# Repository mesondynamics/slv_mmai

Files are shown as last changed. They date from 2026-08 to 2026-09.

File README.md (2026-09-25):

# Mobile Machine Actuation Interface

**English** · [简体中文](README.zh-CN.md)

A hardware/software interface for retrofitting remote or autonomous control onto
electromechanical and electrohydraulic mobile machines.

MMAI command, actuation, and feedback architecture

MMAI connects an upper-level controller to the steering, propulsion, auxiliaries,
and available state feedback of an existing machine. This repository presents
the engineering approach through schematics, firmware, interface code, and its
development history. Read the source as working design material: it records the
hardware, communication, and actuation choices behind the ECU.

## What it does

- Receives commands from teleoperation or autonomy software.
- Validates commands and manages control authority, timeouts, and output enable.
- Maps commands to electrical interfaces such as relays, CAN-controlled actuators,
  or PWM-driven hydraulic valve coils.
- Acquires machine and actuator state and sends feedback to the upper layer.
- Keeps low-level machine behavior understandable independently of a planner.

The same architecture can be adapted to street sweepers, compactors, agricultural
machines, utility vehicles, and other mobile equipment. The appropriate actuator,
wiring, feedback, and stop behavior depend on the machine. Analog command outputs
or additional serial interfaces are adaptation options, not capabilities implied
for every board in this repository.

## Architecture

The machine-interface ECU sits between the command source and the physical
machine. Steering, propulsion, and auxiliary I/O are separate adaptation paths;
state feedback closes the path through the ECU. Existing manual controls and
machine interlocks are part of that integration.

Upper-level navigation, perception, and route planning are outside the core
actuation boundary. The retained implementation focuses on low-level actuation
and state feedback. See [Architecture](docs/architecture.md)
and [Interfaces](docs/interfaces.md).

## Implementation map

| Area | Start here | What to look for |
| --- | --- | --- |
| H563 actuation ECU | [Hardware project](pcb/roller/ecu/PROJECT1.kicad_pro), [firmware](firmware/roller/ECU/) | Relay switching, proportional-valve current control, CAN steering, protected control boundary |
| Mechanical material | [CAD](cad/), [PCB sources](pcb/) | Physical integration and board development |

Historical directory names are retained so code, drawings, and commits remain
easy to trace. They do not define the scope of the general architecture.

## A useful reading order

1. Read the [hardware guide](docs/hardware.md) and open the corresponding schematic.
2. Follow a command through the [firmware guide](docs/firmware.md): parser, control
   policy, machine mapping, then physical driver.
3. Follow feedback in the opposite direction, checking units and validity flags.
4. Compare earlier revisions using the [project history](docs/PROVENANCE.md).
5. Use the [porting guide](docs/porting-guide.md) to describe a different machine.

The H563 example includes an Ethernet command/state protocol, CAN interfaces,
relay/contact outputs, PWM valve drivers with current sensing, and analog,
discrete, and pulse inputs. Its wire protocol and I/O assignments are concrete
implementation choices; they are not a universal machine API.

## Safety and bench exploration

This is experimental engineering material, not a certified functional-safety
controller or a ready-to-install vehicle conversion. Physical deployment needs
machine-specific engineering. Begin any electrical exploration with isolated
signals and dummy loads, and understand startup, command-loss, manual-control,
and emergency-stop behavior before connecting actuators. See [Safety](docs/SAFETY.md).

## History and related work

The repository lineage begins in 2024. The public source centers on the
machine-interface ECU hardware and firmware, with retained design revisions
and technical notes. [Provenance](docs/PROVENANCE.md) identifies source milestones.

Electronic and electrohydraulic machine actuation has a long public engineering
history. [Prior art and related systems](docs/PRIOR_ART.md) provides technical
references for understanding these established approaches.

## License and contributions

Original project contributions use [BSD-2-Clause](LICENSE), subject to existing
file-specific notices. Bundled third-party material retains its own terms and
attribution; see the [license index](LICENSES/README.md).

Corrections, explanations, and clearly attributed design contributions are welcome.
See [Contributing](CONTRIBUTING.md) and [Security](SECURITY.md).

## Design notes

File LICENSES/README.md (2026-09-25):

# License scope and existing notices

The root [BSD-2-Clause license](../LICENSE) covers original MMAI contributions,
including original source, design files, and documentation, except where a file
already specifies other terms. "MMAI contributors" refers to the respective
contributors; existing copyright notices and author attribution remain in force.

The root license does not relicense third-party source, documents, images,
libraries, or models. Their respective notices and terms continue to apply.

| Component or collection | Existing notice |
| --- | --- |
| H563 Arm CMSIS | [CMSIS license](../firmware/roller/ECU/Drivers/CMSIS/LICENSE.txt) |
| H563 ST device support | [Device license](../firmware/roller/ECU/Drivers/CMSIS/Device/ST/STM32H5xx/LICENSE.txt) |
| H563 ST HAL | [HAL license](../firmware/roller/ECU/Drivers/STM32H5xx_HAL_Driver/LICENSE.txt) |
| LAN8742 support | [Component license](../firmware/roller/ECU/Drivers/BSP/Components/lan8742/LICENSE.md) |
| LwIP | [COPYING](../firmware/roller/ECU/ThirdParty/LwIP/COPYING) |
| ECU LIB1 collection | [Supplied library terms](../pcb/roller/ecu/libraries/LIB1/LICENSE1.txt) |

This index points to existing notices; individual files and other hardware
generations may carry additional notices. References to external work are
attribution, not a change to that work's license.

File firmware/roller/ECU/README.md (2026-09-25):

# STM32H563 actuation ECU firmware

[MMAI overview](../../../README.md) · [Firmware reading guide](../../../docs/firmware.md)

This project implements an actuation interface with Secure and NonSecure firmware
domains, an Ethernet command/state interface, relay outputs, proportional-valve
current control, and CAN-connected machine/actuator paths.

## Read the implementation

| Area | Entry point |
| --- | --- |
| Command framing and parsing | [ecu_protocol.h](NonSecure/App/Inc/ecu_protocol.h), [ecu_protocol.c](NonSecure/App/Src/ecu_protocol.c) |
| Network handling | [ecu_network.c](NonSecure/App/Src/ecu_network.c) |
| Protected interface | [safety_api.h](Secure_nsclib/safety_api.h) |
| Output policy and interlocks | [safety_service.c](Secure/App/Src/safety_service.c), [run_permit_policy.c](Secure/App/Src/run_permit_policy.c) |
| Valve-current loop | [valve_control.c](Secure/App/Src/valve_control.c) |
| Steering control | [steering_control.c](Secure/App/Src/steering_control.c), [steering_can.c](Secure/App/Src/steering_can.c) |
| Machine CAN feedback | [vehicle_can.c](Secure/App/Src/vehicle_can.c) |
| Boot/update layout | [ecu_flash_layout.h](Shared/ecu_flash_layout.h), [OEMiROT](Bootloader/OEMiROT/) |

Trace each requested output through the parser, authority/enable policy, machine
mapping, and driver. For feedback, trace the physical input through scaling,
validity/freshness, and state encoding. Manual run permission and automatic-output
enable are distinct decisions in this implementation.

## Design context

The project contains STM32CubeMX/CMake inputs, vendor support, host tools, and
historical tests. They describe a particular hardware generation and its original
engineering assumptions. Device profiles and wiring mappings are examples of
integration-specific configuration, not universal defaults.

The retained detailed notes include the original Chinese
[protocol and UI description](docs/ECU_Protocol_and_UI.md),
[boot/update design](docs/ECU_Security_and_OTA.md), and
[bench-method notes](docs/ECU_Bench_Acceptance.md). The English
[interface guide](../../../docs/interfaces.md) gives the main protocol boundaries.

Before using manufacturing, recovery, update, or control tools, understand their
physical effects and the target hardware. See [Safety](../../../docs/SAFETY.md).

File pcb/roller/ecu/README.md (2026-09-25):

# Actuation interface ECU hardware

**English** · [中文设计说明与完整参考资料](README.zh-CN.md)

This STM32H563-based board illustrates the electrical boundary between an
upper-level controller and existing machine actuators and sensors. Open
[PROJECT1.kicad_pro](PROJECT1.kicad_pro) and the
[root schematic](PROJECT1.kicad_sch) to explore the design.

The [hardware reading guide](../../../docs/hardware.md) maps the nine schematic
sheets to their functions. The [architecture](../../../docs/architecture.md)
places the board in the larger steering, propulsion, and auxiliary-I/O system.

## Design paths

- **Steering:** connect to a supported external actuator/controller; mechanical
  coupling and feedback depend on the machine.
- **Propulsion:** the reference circuit drives two proportional-valve coils with
  PWM and current sensing. The machine's hydraulic circuit determines how coil
  current affects propulsion.
- **Auxiliaries:** a serial driver chain and relay contacts can switch or select
  existing machine signals. Wiring and contact assignments remain machine-specific.
- **Feedback:** analog, temperature, isolated digital, pulse, and bus interfaces
  provide the inputs available to the selected integration.

## Circuit-source notes

The original [Chinese technical notes](README.zh-CN.md) include the detailed
PAGE1-PAGE9 circuit mapping, public source identifiers S01-S60, and illustrated
retrofit examples. Selected entry points are:

| Topic | Detailed notes |
| --- | --- |
| Steering actuators | [Motor/steering integration](README.zh-CN.md#steer-sys-01) |
| Proportional-valve drive | [PWM and current-sensing path](README.zh-CN.md#sol-os-01) |
| Relay/contact switching | [Relay interface path](README.zh-CN.md#rly-sys-01) |
| Solenoid reference circuit | [Analog Devices CN0415](README.zh-CN.md#s38) |
| Earlier hydraulic retrofit example | [CASE CX160 project reference](README.zh-CN.md#s60) |

These references explain particular design functions; they do not make all
machine interfaces interchangeable. Consult the selected board revision and
[safety guidance](../../../docs/SAFETY.md) before any physical integration.

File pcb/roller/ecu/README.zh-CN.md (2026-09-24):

# 通用车辆线控改装方案

本项目整理公开的车辆改装方法，并提供一套可复用的开源 ECU 硬件设计。目标是让具备不同转向、行驶和车身信号机构的车辆，经过针对车型的适配后，能够接收外部控制命令并返回状态，从而成为遥控或无人驾驶系统的车辆执行平台。执行装置、原车接口和可获得的反馈都以目标车辆为准。

## 整体方案

车辆线控系统整体架构

转向、行驶和车身信号是三条可分别适配的路径。ECU 接入命令、连接外部执行装置或原车接口，并汇集可取得的状态反馈。遥控与无人驾驶的区别在于命令来源。

## 车辆改装方案

### 转向：电机方向盘

在方向盘位置安装同轴直驱的电机方向盘，使电机通过原车转向柱和转向机构完成转向，并读取电机位置或可用的转角反馈。中空轴/中空电机是可选的机械安装形式；轴径、花键、安装空间与所需扭矩应按车型和所选电机确定。

| 公开案例 | 改装形式 | 对本方案的参考 |
| --- | --- | --- |
| [Keya 工程车辆转向电机](#s51) | 安装于转向轴的直驱电机；资料列举叉车、压路机、推土机 | 工程车辆的电机方向盘路线 |
| [SunNav AG500Pro](#s52) | 电机方向盘替换原方向盘 | 农机的方向盘替换路线 |
| [Smajayu JY305](#s53) | 电机方向盘配合控制器和角度传感器 | 转向执行与角度反馈的组合路线 |

| Keya 转向电机套件 | SunNav AG500Pro 电机方向盘 | Smajayu JY305 装车示例 |
| :---: | :---: | :---: |
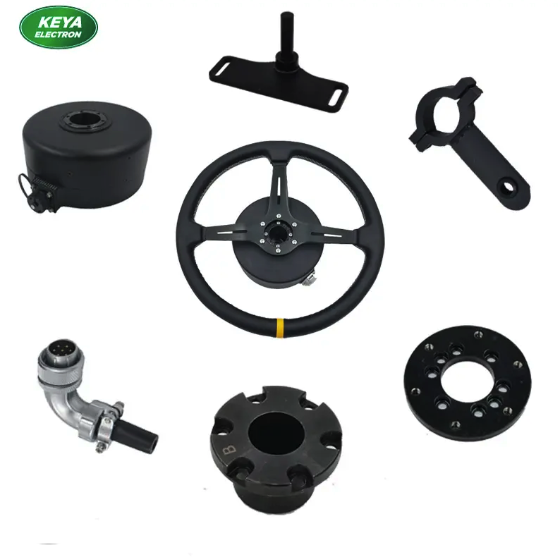
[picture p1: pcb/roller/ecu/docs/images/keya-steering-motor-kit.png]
Keya 转向电机与方向盘套件
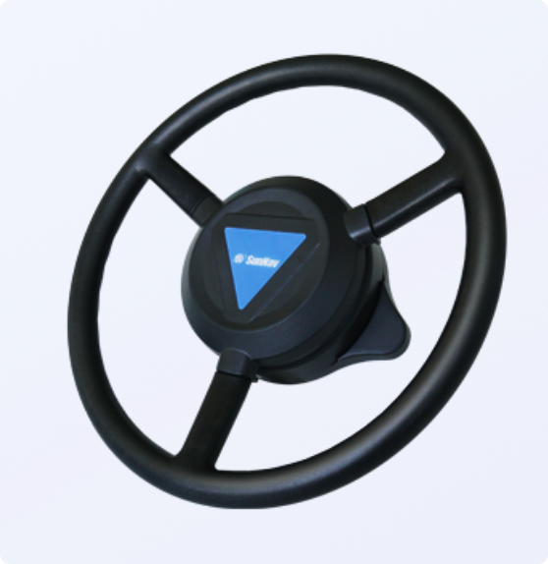
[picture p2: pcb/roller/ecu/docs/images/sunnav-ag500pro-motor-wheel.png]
SunNav AG500Pro 电机方向盘
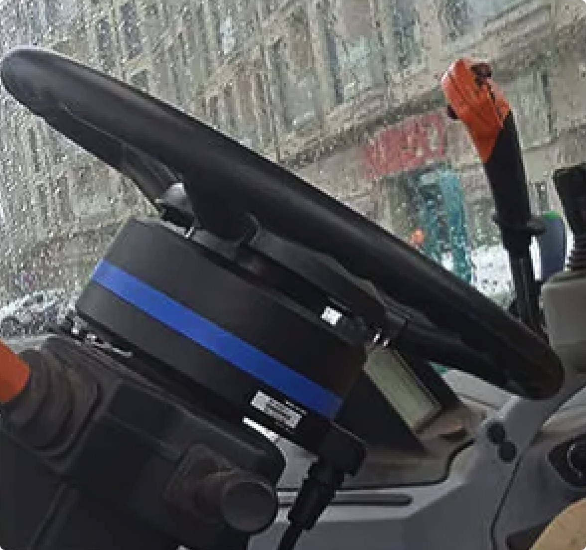
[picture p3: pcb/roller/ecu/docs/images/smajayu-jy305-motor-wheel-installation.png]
Smajayu JY305 电机方向盘装车示例
|  |  |  |

Keya 转向电机的[演示视频](https://www.youtube.com/watch?v=uilSU-zbLFg)。三张产品图分别对应 [S51](#s51)、[S52](#s52)、[S53](#s53)。

### 行驶与速度：本项目方案及其他公开路径

不同车辆接收油门、速度及前进/后退指令的机构不同。下表汇集相应的公开改装路径，供其他车型选择与溯源；**本项目针对所用车辆选择的是在低压先导油路增设比例阀**，本 ECU 设计了与之对应的两路阀线圈驱动和电流采样。其余路径仅为公开案例。

| 原车机构 | 改装路径  | 公开来源 |
| --- | --- | --- |
| 具有低压先导油路的液压行驶机构 | 在先导油路增设比例阀，通过阀线圈电流调节先导压力和原车主阀；具体行驶功能由原车液压回路决定 | [2003 年 CASE CX160 遥控改装](#s60)、[AgOpenGPS 液压硬件](#s48)、[OpenHumidistat 恒流驱动](#s49)、[ADI CN0415](#s38) |
| 机械油门或速度操纵杆 | 用执行器推动原控制件，行程与位置反馈按原车机构适配 | [ROS 2 Autonomous Tractor](#s59) 展示直线执行器控制加速 |
| 原车速度电位器 | 对可接入的速度设定信号，参考模拟速度指令接入方式 | [OpenPodcar](#s43) 展示原车速度电位器的电控接入 |
| 电子节气门或电驱控制器 | 在车型和控制器支持的条件下，使用其可验证的电子控制接口；具体接口依车型而定 | [rusEFI](#s54) 展示电子节气门链路；[OVCS](#s55) 展示电驱车辆多部件 CAN 集成 |

2003 年弗吉尼亚理工大学公开的 [CASE CX160 挖掘机遥控改装报告](#s60) 是液压车辆的实车案例：团队在原车低压先导油路增加电液比例阀，通过先导压力控制主阀，进而遥控左右履带和工作装置。报告还记录了液压改装、电气控制及实车调试。该案例说明比例阀路线早已用于工程车辆遥控改装；是否适用其他车辆，取决于其液压系统是否提供合适的先导控制接入点。

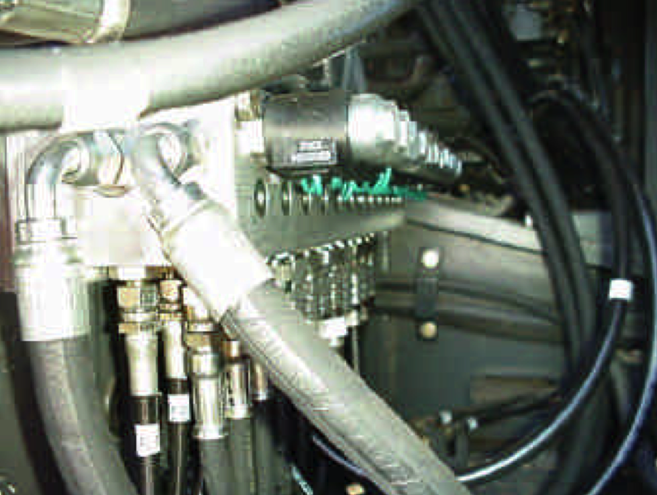
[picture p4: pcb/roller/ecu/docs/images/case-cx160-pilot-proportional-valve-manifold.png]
CASE CX160 挖掘机先导油路比例阀集成块实物


*图：CASE CX160 改装中的比例阀集成块实物；项目维护者提供的截图，参见 [2003 年改装报告](#s60) Figure 5-6。*

速度反馈与速度命令是不同的接口。公开方案中，车速可来自可解析的原车 CAN、车速脉冲或独立速度传感器；[RetroPilot Ocelot](#s56) 展示了原始 VSS 输入与已有 CAN 信息的转换。本项目车辆最终采用的车速反馈及前进/后退信号接法，仍需依据原车接口确定；上述来源不表示所有反馈路径均已在本 ECU 上完成接入。

### 灯光、喇叭与其他原车信号

对于需要切断原路径再切换到外部控制的信号，可用继电器接入；只需新增通断控制的信号，可按原车接口选用受控电源或接地。[OpenPodcar](#s43) 的车辆继电器接入与 [Subaru BRZ VCU](#s45) 的继电器、信号复用设计提供公开参考。

另一条路径是使用原车或已有线控系统提供的 CAN 接口。[PACMod3 公开驱动](#s58) 列出了灯光、喇叭、危险警示灯等命令；[opendbc](#s57) 展示车型相关的 CAN 消息定义。CAN 控制仅适用于已确认支持相应命令的车型或控制系统，不能把某车型的消息直接视为通用接口。继电器和 CAN 可在同一车辆上分别负责不同信号。

### 状态反馈

整车可按现有接口取得方向盘或车轮转角、车速、行驶执行装置状态、灯光/喇叭等原车信号状态。反馈可来自执行装置控制器、原车 CAN、车速脉冲、开关量或模拟传感器；公开的 [OVCS](#s55) 与 [RetroPilot Ocelot](#s56) 展示了多种原车与外加接口并用的方式。并非所有车辆都提供上述全部状态，实际可用项由车型接口确定。

## ECU：车辆连接中枢

ECU 接收外部命令，通过通信接口与外部执行装置或原车控制系统连接，通过自身输出连接点击、继电器及针对低压先导油路改装的两路比例阀，并采集可接入的模拟量、数字量和脉冲量。

### 比例阀驱动电路

本 ECU 的两路比例阀驱动主要面向**在车辆低压先导油路增设电液比例阀**的改装方式：PAGE7 为两个阀线圈提供低边驱动及电流采样硬件，通过调节先导压力影响原车主阀。此设计参考 [2003 年 CASE CX160 案例](#s60) 的液压接入思路；该案例使用 12 个阀及独立阀控制器，本 ECU 的两路硬件并非整套挖掘机液压控制系统。两路阀的用途、行驶方向映射及所需电流范围，仍由目标车辆的先导油路和主阀决定。

[ADI CN0415](#s38) 是比例电磁阀驱动的主要公开参考：其说明了 PWM、线圈电流监测、闭环控制和 dither。CN0415 采用低边开关与高边分流采样；本项目借鉴功能链路，在 PAGE7 使用低边分流采样。[S21](#s21)、[S39](#s39)、[S40](#s40)、[S41](#s41) 和 [S42](#s42) 补充电流检测与汽车比例阀资料。

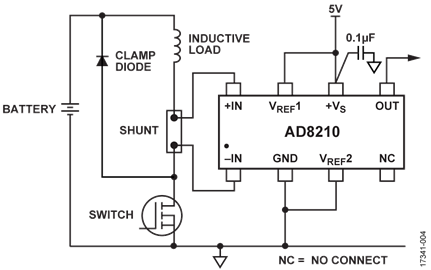
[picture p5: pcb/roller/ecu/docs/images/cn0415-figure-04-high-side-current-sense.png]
CN0415 高边电流采样与低边开关


*图源：[Analog Devices CN0415](https://www.analog.com/en/resources/reference-designs/circuits-from-the-lab/cn0415.html#rd-description)，Figure 4。*

本项目以 PWM 控制低边 MOSFET，并测量线圈电流；[OpenHumidistat](#s49)、[PneuSoRD](#s47) 和 [AgOpenGPS](#s48) 提供可追溯的公开实现参考。

### 继电器驱动与信号切换来源

PAGE5 的串行低边驱动链连接 PAGE6 的继电器触点。继电器可用于原车信号断开与替代信号切换，也可为无需切断的信号提供受控电源或接地；具体触点功能由车型连接表决定。[OpenPodcar](#s43)、[Subaru BRZ VCU](#s45) 和 [relay_matrix_edsp](#s46) 是公开系统参考，[TPIC6A595](#s13) 与 [SN74AHCT541-Q1](#s37) 提供驱动器件依据。

### 电路来源的使用方式

本文区分器件厂商资料、开源实现和公开商业产品。来源编号用于追溯。以下等级仅用于 ECU 电路的来源映射。

| 等级 | 含义 | 在本项目中的用途 |
| --- | --- | --- |
| A | 同型号器件的官方典型应用、参考原理图或评估板与本页拓扑近似 | 电路拓扑和关键连接依据 |
| B | 同型号官方数据手册/应用笔记给出的连接规则、接口电路或设计方法 | 局部电路、器件选型和控制方法依据 |
| C | 公开的通用原理、相邻型号资料或器件能力说明 | 工程实现方向，参数仍需验证 |

### ECU 电路与公开来源映射

下表按原理图 PAGE 列出 ECU 已有电路及公开依据。

### PAGE1 — 电源变换与状态指示

| ID | 电路与覆盖范围 | 公开依据（文档定位） | 等级 | 本项目实现说明 |
| --- | --- | --- | --- | --- |
| P1-01 | 高电流同步降压：`U8`、`L2` 及其输入、输出、反馈、频率设定和去耦网络 | [S01](#s01)，Figure 10，p.69 | A | 同为 MPQ4371-1000 的 5 V、2.2 MHz 典型应用；反馈、频率设定、输入/输出电容结构高度一致。工程中的器件额定值、并联数量及使能/模式配置需以原理图和负载验证为准。 |
| P1-02 | 小功率同步降压：`U9`、`L1` 及 `C7,C10-C12,C14-C18,C23,C25,C26,R23-R30,R32,R33,R50,R60,R61,R64` | [S02](#s02)，Application Information 与 Typical Application Circuits，pp.21–25 | A | 拓扑、软启动、反馈、输入/输出去耦与 MPQ2178 典型应用一致。 |
| P1-03 | 两组电源良好/状态指示与开漏缓冲：`Q1,Q9,D7,D14,R34,R35,R63,R65,R66` | [S01](#s01)，Power Good；[S02](#s02)，Power Good；[S15](#s15)，MOSFET switching application | B | 本项目依据开漏状态输出和外部上拉规则设计 LED 与小信号 MOSFET 指示级，具体电阻和指示方式由工程需求确定。 |

### PAGE2 — MCU、时钟、复位、调试与安全器件

| ID | 电路与覆盖范围 | 公开依据（文档定位） | 等级 | 本项目实现说明 |
| --- | --- | --- | --- | --- |
| P2-01 | MCU 供电、模拟参考、内部稳压电容与就地去耦：`U1` 及 `C6,C28-C46,C51,R36,R37` | [S03](#s03)，Figures 2、15、19，pp.5、36、40 | A | AN5711 明确覆盖 STM32H563 系列的电源域、参考设计和去耦布局；具体电容分配需结合所用封装引脚逐项核对。 |
| P2-02 | 外部复位按键、上拉/滤波与 ESD：`SW1,D1,R49,C46` | [S03](#s03)，Figure 9，p.15；[S28](#s28) | B | 复位网络符合 STM32H5 硬件指南，ESD 器件能力由其官方数据手册支持；保护等级仍取决于布局与脉冲源阻抗。 |
| P2-03 | 启动配置跳线：`JP1` 及相邻配置电阻 | [S03](#s03)，Boot configuration，p.26 | B | 文档给出启动脚配置原则；跳线形式及默认状态是工程选择。 |
| P2-04 | 25 MHz 高速外部晶振：`Y2,C47,C48` | [S04](#s04)，§§3–4（Pierce oscillator、load capacitance、crystal selection） | B | 结构符合 Pierce 振荡器；负载电容必须按晶体 CL、引脚和 PCB 寄生重新核算。 |
| P2-05 | 32.768 kHz 低速外部晶振：`Y1,C49,C50` | [S04](#s04)，§§3–4；[S03](#s03)，clock recommendations | B | 结构与低速晶体网络一致；低功耗晶体的驱动裕量和负阻测试不由原理图本身证明。 |
| P2-06 | SWD 调试接口：`J1` | [S03](#s03)，Figure 12，p.30 | A | 信号集合与 STM32H5 官方 SWD 连接方式一致；连接器针序是项目实现。 |
| P2-07 | I²C 安全器件及去耦/上拉：`U221,R105,R106,C45` | [S05](#s05)，Figure 1 与 Table 1；[S06](#s06)，DT100104 schematic，sheet 1 | A | 官方板原理图展示 ATECC608C 的 I²C、上拉和 100 nF 去耦。地址/配置区内容不在原理图可追溯范围内。 |

### PAGE3 — 10/100 Ethernet PHY 与物理接口

| ID | 电路与覆盖范围 | 公开依据（文档定位） | 等级 | 本项目实现说明 |
| --- | --- | --- | --- | --- |
| P3-01 | RMII PHY、偏置、内部稳压电容与电源滤波：`U4,FB1,R53,C54-C63` 及相邻去耦 | [S07](#s07)，p.13 与 Figures 3-20、3-21，pp.53–54 | A | 12.1 kΩ RBIAS、内部 1.2 V 稳压电容和单电源连接与 LAN8742A 官方应用图一致。 |
| P3-02 | PHY 25 MHz 晶振：`Y3,C52,C53` | [S07](#s07)，clock/oscillator sections；[S04](#s04)，§§3–4 | B | PHY 数据手册规定时钟接口，AN2867提供晶体负载核算方法；实际起振裕量需测试。 |
| P3-03 | MDI 端接、共模磁性器件与外部连接器：`R58,R59,R67,R68,R54-R56,C64,T201,J3` | [S07](#s07)，Figure 3-23，p.56；[S08](#s08)；[S09](#s09) | A | 49.9 Ω 端接、磁性器件、Bob Smith 类端接与官方单电源双绞线接口图一致；连接器由项目改为 M12 X-code，针序须按其图纸核对。 |
| P3-04 | 高速线 ESD 保护：`U5` | [S10](#s10)，Application Diagrams 与 PCB layout recommendations | B | USBLC6-4 的低电容多线保护结构可用于高速差分接口；具体 IEC 等级依赖布局，且该器件名称并不把用途限定为 USB。 |
| P3-05 | PHY 状态 LED 与串联电阻：`D19,D20,R51,R57` | [S07](#s07)，LED pins/configuration | B | PHY 提供 LED 输出及配置说明；颜色、亮度和电阻值为工程选择。 |
| P3-06 | RMII 串联阻尼/配置电阻：`R38-R48,R69,R70,R113-R115` | [S07](#s07)，RMII interface、strap inputs 与 layout guidance | B | 数据手册支持启动配置和数字接口布线原则；33 Ω 阻尼值须结合走线阻抗和边沿测量确认。 |

### PAGE4 — 两路 CAN 物理层

| ID | 电路与覆盖范围 | 公开依据（文档定位） | 等级 | 本项目实现说明 |
| --- | --- | --- | --- | --- |
| P4-01 | 两个同构 CAN 收发与可配置 120 Ω 端接通道：`U13,U14,C40,C85,R42,R43,R107,R108` | [S11](#s11)，Figures 38–39，p.27 | A | 官方图给出 CAN 总线与 120 Ω 端接原则；0 Ω 配置电阻使端接是否接入由装配方案决定。该物理接口可连接具备 CAN 接口的外部装置或经确认的原车 CAN 总线；协议与总线分配按车型确定。 |
| P4-02 | 两路 CAN 线对浪涌/ESD 保护：`D21,D22` | [S12](#s12)，High-Speed/Fault-Tolerant CAN Surge Protection application figure | A | NUP2105L 官方应用图即为 CANH/CANL 双线保护；最终抗扰度仍需结合接地回路和 PCB 布局验证。 |

### PAGE5 — 继电器驱动逻辑与串行低边驱动

| ID | 电路与覆盖范围 | 公开依据（文档定位） | 等级 | 本项目实现说明 |
| --- | --- | --- | --- | --- |
| P5-01 | 继电器驱动前端与四片低边驱动器组合链：`U300,U301-U304,Q6,C5,C21,C66-C68,R71-R78` | [S14](#s14)，Function Table、三态输出与电源建议；[S37](#s37)，SN74AHCT541-Q1 产品资料；[S13](#s13)，§7.3.3、§7.3.4，p.13 | B | 本项目使用 `SN74AHCT541QPWRQ1` 完成受使能控制的并行逻辑，使用 `TPIC6A595DWR` 完成串入并出、开漏低边输出、感性负载钳位和级联，形成四片低边继电器驱动链。 |
| P5-02 | TPIC 输出级及四片级联：`U301-U304,C5,C21,C66,C67,R71-R74` | [S13](#s13)，§7.3.3 与 §7.3.4 Cascaded Application，p.13 | A | SER OUT 到下一片 SER IN、低边开漏 DMOS 和感性负载钳位均由官方资料明确给出；负载数量与映射为工程定制。 |
| P5-03 | 小信号 MOSFET 控制/电平处理：`Q6,R77` | [S15](#s15)，Description and Applications | C | 本项目依据器件的开关和电源管理能力完成电平处理，Q6/R77 的阈值、速度和负载条件在样机测试中验证。 |

### PAGE6 — 继电器触点矩阵与电源储能

| ID | 电路与覆盖范围 | 公开依据（文档定位） | 等级 | 本项目实现说明 |
| --- | --- | --- | --- | --- |
| P6-01 | 继电器触点矩阵：`K1-K27` | [RLY-SYS-01](#rly-sys-01)；[S16](#s16) | — | 本项目重点记录矩阵的驱动、切换行为和安全时序；逐触点组合由工程连接表维护，车辆信号断开、替代切换、直接电源/地接入见 RLY-SYS-01。 |
| P6-02 | 继电器电源母线储能：`C22,C69-C71` | [S17](#s17)，Input and Output Capacitor Selection，bulk-capacitance discussion | C | 并联大容量电容符合负载阶跃储能的一般原则；容量、ESR、纹波电流、浪涌及故障能量必须按实际继电器同时动作数验证。 |

### PAGE7 — 两路功率低边驱动与电流检测

| ID | 电路与覆盖范围 | 公开依据（文档定位） | 等级 | 本项目实现说明 |
| --- | --- | --- | --- | --- |
| P7-01 | 两个比例电磁阀低边驱动通道：`U10,U11,Q2,Q3,D2,D3,R79-R82,C72-C75` | [比例阀低边恒流驱动](#sol-os-01)；[S38](#s38)；[S18](#s18)，Typical Application；[S19](#s19)；[S20](#s20) | B | 本项目采用 UCC27517A-Q1 控制 N-MOSFET，STPS5L60SY 提供续流路径，并以闭环电流建立比例阀控制量；CN0415 提供 PWM、dither、栅极驱动和过流保护的系统级参考。 |
| P7-02 | 两路 50 mΩ 分流电阻与 INA240 电流检测：`R1,R2,U6,U12,R83,R84,C76,C77` | [比例阀低边恒流驱动](#sol-os-01)；[S38](#s38)；[S21](#s21)，§9.2.2、§9.3.2；[S22](#s22) | B | 本项目采用 INA240 的 PWM 抑制和 Kelvin 采样方法；分流器为 50 mΩ、3 W，采样增益、量程、功耗和滤波按实际阀线圈验证，功能链路对应 CN0415 的电流监测和闭环控制。 |

### PAGE8 — 模拟量、温度、隔离量与脉冲输入

| ID | 电路与覆盖范围 | 公开依据（文档定位） | 等级 | 本项目实现说明 |
| --- | --- | --- | --- | --- |
| P8-01 | 四个同构的受保护模拟输入：`D4,D9,R85,R86,R94,C78`；`D12,D13,R91,R97,R98,C82`；`D15,D16,R99-R101,C83`；`D17,D18,R102-R104,C84` | [S23](#s23)，ADC input impedance/RC guidance；[S24](#s24)；[S25](#s25) | B/C | 本项目采用分压、串联限流、RC 低通和轨钳位构成 MCU ADC 前端；`ESD5V0D5` 当前按同型号公开参数建库，最终订货号在 BOM 阶段确认。 |
| P8-02 | 两个同构 NTC 分压/滤波输入：`J2,R109,R110,C86`；`J4,R111,R112,C87` | [S26](#s26)，Monitoring NTC Thermistor Circuit With Single-Ended ADC | B | 电阻分压与 ADC 输入电容的结构一致；NTC 的 B 值、标称阻值、线束电阻和温度换算表须由实际探头补充。 |
| P8-03 | 电源电压分压、RC 滤波与双肖特基钳位：`R92,R93,R95,R96,C79,D10` | [S23](#s23)，ADC input protection/RC guidance；[S24](#s24) | B | 结构符合高压量测的电阻分压和限流钳位原则；量程与故障注入电流需按 ADC 绝对最大额定值重新计算。 |
| P8-04 | 光耦隔离数字输入：`R117,R118,U15,R121,R122,C80` | [S27](#s27)，Figure 1 switching test circuit 与 electrical characteristics；[S31](#s31) | B | 输入限流、光晶体管输出上拉和滤波有器件/应用资料支持；阈值、CTR 老化裕量与现场电压范围是项目参数。 |
| P8-05 | 受保护的脉冲整形输入：`D8,R87,R88,D11,Q4,R89,C81,U7,R90` | [S29](#s29)，Schmitt-trigger input；[S30](#s30)；[S24](#s24) | B/C | 本项目使用 TVS/肖特基限制瞬态，使用 BJT 完成电平和电流处理，再由施密特反相器恢复边沿；整体按 C 级组合电路进行验证，各器件规则按 B 级执行。 |

### PAGE9 — 电源入口、反接保护与连接/机械件

| ID | 电路与覆盖范围 | 公开依据（文档定位） | 等级 | 本项目实现说明 |
| --- | --- | --- | --- | --- |
| P9-01 | 入口双向 TVS 与高低频旁路：`D5,C88,C89` | [S32](#s32)，SMCJ24CA-Q electrical characteristics；[S17](#s17) | B | 器件型号对应 24 V、1500 W、双向汽车级 TVS；电容并联用于宽频旁路。整机脉冲等级仍取决于源阻抗、线束和布局。 |
| P9-02 | 理想二极管控制器与外部 N-MOSFET 反接/反向电流保护：`U2,Q5` | [S33](#s33)，Typical Application Schematic 与 Figure 3；[S34](#s34) | A | LM74700-Q1 官方典型图即采用外部 N 沟道 MOSFET，并包含入口 TVS/电容；所选 60 V MOSFET 的耐压、导阻和热设计需针对实际浪涌复核。 |
| P9-03 | 两个密封板端连接器：`J6,J7` | [S35](#s35)；[S36](#s36) | A | 厂商页面/图纸分别确认 35 位和 23 位 AMPSEAL 直角板端连接器。针位的电气分配属于工程定义。 |
| P9-04 | 带焊盘安装孔：`H1-H4` | 本工程机械/接地实现，无唯一外部参考电路 | C | 位号覆盖完整；是否连接机壳、保护地或信号参考必须结合 PCB、结构和 EMC 方案判断。 |

## 公开来源

S01–S50 的访问日期为 **2026-09-17**；S51–S60 的访问日期为 **2026-09-24**。

### 开源实现来源

| 来源 | 许可证/开放方式 | 本项目采用的设计要点 |
| --- | --- | --- |
| [S43](#s43) OpenPodcar | 软件 GPL-2.0，硬件 CERN-OHL-W | 原车速度电位器/DAC 接入、转向执行器与继电器接入 |
| [S46](#s46) relay_matrix_edsp | MIT | 交叉点矩阵、级联驱动、互斥命令和状态查询 |
| [S47](#s47) PneuSoRD | MIT | 比例阀 PWM、降压功率级、过流保护和多通道驱动 |
| [S48](#s48) HW_for_AgOpenGPS | CERN-OHL-S-2.0（硬件） | 双 PWM 液压比例阀、反馈控制和开源农机执行器接口 |
| [S49](#s49) OpenHumidistat/hardware | CERN-OHL-S-2.0 | 两路低边 VCCS 恒流比例阀驱动、KiCad 原理图/PCB/BOM |
| [S50](#s50) OpenHumidistat 论文 | 公开论文与配套开源设计 | PWM 输入、恒流控制、温升补偿和比例阀闭环方法 |
| [S54](#s54) rusEFI | 公开项目与文档 | 电子节气门、踏板和节气门位置反馈 |
| [S55](#s55) OVCS | MIT | 电驱车辆的多部件 CAN 集成与状态读取 |
| [S56](#s56) RetroPilot Ocelot | 公开项目资料 | 原车 CAN、VSS 脉冲、继电器接口的组合 |
| [S57](#s57) opendbc | 开源项目 | 车型相关的 CAN 信号定义与解析 |
| [S58](#s58) PACMod3 驱动 | 公开驱动代码 | 支持平台的灯光、喇叭等车身命令接口 |
| [S59](#s59) ROS 2 Autonomous Tractor | 公开项目与文档 | 以直线执行器控制拖拉机加速的案例 |

### 公开商业产品案例

| 来源 | 公开案例 | 在整车方案中的用途 |
| --- | --- | --- |
| [S51](#s51) Keya | 工程车辆方向盘直驱电机 | 转向轴直驱、内置控制器和 CAN 接口参考 |
| [S52](#s52) SunNav AG500Pro | 农机电机方向盘 | 方向盘替换结构和外形、扭矩规格参考 |
| [S53](#s53) Smajayu JY305 | 农机自动转向套件 | 电机方向盘、控制器和角度传感器组合参考 |

### 公开学术改装案例

| 来源 | 实车案例 | 在整车方案中的用途 |
| --- | --- | --- |
| [S60](#s60) CASE CX160（2003） | 低压先导油路加装比例阀的挖掘机遥控改装 | 液压工程车辆的比例阀接入和实车应用参考 |

### 详细来源条目

本节列出机构/作者、文献题名、版本或章节定位和原始链接；具体电路与本项目的对应关系见上方 ECU 映射，整车使用方式见车辆改装方案。

**S01 — Monolithic Power Systems, MPQ4371-AEC1 Datasheet**, Rev. 1.0 (2024-03-21), Figure 10 “Typical Application Circuit for MPQ4371-1000”, p. 69.<br>
https://www.monolithicpower.com/en/documentview/productdocument/index/version/2/document_type/Datasheet/lang/en/sku/MPQ4371GVE-AEC1/

**S02 — Monolithic Power Systems, MPQ2178-AEC1 Datasheet**, Rev. 1.1 (2023-05-04), Application Information; Typical Application Circuits, pp. 21–25.<br>
https://www.monolithicpower.com/en/documentview/productdocument/index/version/2/document_type/Datasheet/lang/en/sku/MPQ2178GQHE-AEC1/

**S03 — STMicroelectronics, AN5711: Getting started with STM32H5 MCU hardware development**, Rev. 3, Figures 2, 9, 12, 15, 19.<br>
https://www.st.com/resource/en/application_note/an5711-getting-started-with-stm32h5-mcu-hardware-development-stmicroelectronics.pdf

**S04 — STMicroelectronics, AN2867: Oscillator design guide for STM8AF/AL/S, STM32 MCUs and MPUs**, Rev. 21, §§ 3–4.<br>
https://www.st.com/resource/en/application_note/an2867-oscillator-design-guide-for-stm8afals-stm32-mcus-and-mpus-stmicroelectronics.pdf

**S05 — Microchip, CryptoAuthentication ATECC608C Summary Data Sheet**, DS40002513, Figure 1; Table 1.<br>
https://ww1.microchip.com/downloads/aemDocuments/documents/SCBU/ProductDocuments/DataSheets/ATECC608C-CryptoAuthentication-Summary-Data-Sheet-DS40002513.pdf

**S06 — Microchip, DT100104 Schematic**, Rev. 5 (2024-05-06), sheet 1.<br>
https://ww1.microchip.com/downloads/aemDocuments/documents/SCBU/ProductDocuments/BoardDesignFiles/DT100104-Schematic.PDF

**S07 — Microchip, LAN8742A/LAN8742Ai Datasheet**, DS00001989A, § 3.9, Figures 3-20, 3-21, 3-23.<br>
https://www.microchip.com/content/dam/mchp/documents/OTH/ProductDocuments/DataSheets/DS_LAN8742_00001989A.pdf

**S08 — Bourns, SM91071AL 10/100 Base-T Transformer Datasheet**.<br>
https://www.bourns.com/docs/product-datasheets/sm91071al.pdf

**S09 — Cinch Connectivity Solutions, SS-12400-004 product page and drawings**.<br>
https://www.cinch.com/products/ethernet-usb/connectors/m-series-connectors/ss-12400-004

**S10 — STMicroelectronics, USBLC6-4 Datasheet**, application diagrams; layout recommendations.<br>
https://www.st.com/resource/en/datasheet/usblc6-4.pdf

**S11 — Texas Instruments, SN65HVD230/SN65HVD231/SN65HVD232 Datasheet**, Rev. O, Figures 38–39, p. 27.<br>
https://www.ti.com/lit/ds/symlink/sn65hvd230.pdf

**S12 — onsemi, NUP2105L Dual Line CAN Bus Protector Datasheet**, High-Speed/Fault-Tolerant CAN Surge Protection application figure.<br>
https://www.onsemi.com/download/data-sheet/pdf/nup2105l-d.pdf

**S13 — Texas Instruments, TPIC6A595 Power Logic 8-Bit Shift Register Datasheet**, Rev. C, §§ 7.3.3–7.3.4, p. 13.<br>
https://www.ti.com/lit/ds/symlink/tpic6a595.pdf

**S14 — Texas Instruments, SN74AHCT541 Octal Buffer/Driver Datasheet**, function table; application information.<br>
https://www.ti.com/lit/ds/symlink/sn74ahct541.pdf

**S15 — Diodes Incorporated, 2N7002KQ Datasheet**, DS43528, Description and Applications.<br>
https://www.diodes.com/datasheet/download/2N7002KQ.pdf

**S16 — Hongfa, HFV6 Automotive Relay product page/data sheet**, 1 Form A; 1 Form C; ratings.<br>
https://www.hongfa.com/Product/automotive-relay/HFV6

**S17 — Texas Instruments, SLTA055: Input and Output Capacitor Selection**, bulk-capacitance; ESR selection.<br>
https://www.ti.com/lit/pdf/slta055

**S18 — Texas Instruments, UCC27517A-Q1 Single-Channel Low-Side Gate Driver Datasheet**, Typical Application.<br>
https://www.ti.com/lit/ds/symlink/ucc27517a-q1.pdf

**S19 — onsemi, NVD5C684NL 60 V N-Channel MOSFET Datasheet**, Rev. 2 (2024-07).<br>
https://www.onsemi.com/download/data-sheet/pdf/nvd5c684nl-d.pdf

**S20 — STMicroelectronics, STPS5L60-Y Automotive Power Schottky Rectifier Datasheet**, Doc ID 022951 Rev. 1.<br>
https://www.st.com/resource/en/datasheet/stps5l60-y.pdf

**S21 — Texas Instruments, INA240 Datasheet**, Rev. C, § 9.2.2, Figure 9-5.<br>
https://www.ti.com/lit/ds/symlink/ina240.pdf

**S22 — TE Connectivity, TLRP3A30DR050FTE product page**, 0.05 Ω, 3 W, 1% current-sense resistor; document ENG_DS_1773449-4_D3.<br>
https://www.te.com/en/product-6-2176422-7.html

**S23 — STMicroelectronics, AN2834: How to optimize the ADC accuracy in the STM32 MCUs**, Rev. 10 (2024-10), ADC source impedance; RC network design.<br>
https://www.st.com/resource/en/application_note/an2834-how-to-optimize-the-adc-accuracy-in-the-stm32-mcus-stmicroelectronics.pdf

**S24 — Diodes Incorporated, BAT54S Datasheet**, DS11005, dual Schottky series configuration.<br>
https://www.diodes.com/assets/Datasheets/ds11005.pdf

**S25 — Micro Commercial Components, ESD3V3D5/ESD5V0D5/ESD7V0D5/ESD12VD5 Datasheet**, Rev. 3 (2019-01).<br>
https://www.mouser.com/datasheet/2/258/ESD3V3D5_7eESD12VD5%28SOD-523%29-V1-1626101.pdf

**S26 — Texas Instruments, SBAA338A: Monitoring NTC Thermistor Circuit With Single-Ended ADC**, Rev. A (2022-06).<br>
https://www.ti.com/lit/an/sbaa338a/sbaa338a.pdf

**S27 — Broadcom, ACPL-214/ACPL-217 Datasheet**, AV02-0469EN, Figure 1; electrical characteristics.<br>
https://docs.broadcom.com/doc/AV02-0469EN

**S28 — Nexperia, PESD5V0S1BA-Q Datasheet**.<br>
https://assets.nexperia.com/documents/data-sheet/PESD5V0S1BA-Q.pdf

**S29 — Texas Instruments, SN74LVC1G14 Datasheet**, Rev. AA, § 6.3.2 “Schmitt-Trigger Inputs”.<br>
https://www.ti.com/lit/ds/symlink/sn74lvc1g14.pdf

**S30 — STMicroelectronics, SM6T Transil Series Datasheet**.<br>
https://www.st.com/resource/en/datasheet/sm6t.pdf

**S31 — Texas Instruments, SLLA420C: How To Simplify Isolated 24-V PLC Digital Input Module Designs**, traditional optocoupler input comparison.<br>
https://www.ti.com/document-viewer/lit/html/SLLA420C

**S32 — Bourns, SMCJ-Q Transient Voltage Suppressor Diode Series Datasheet**, SMCJ24CA-Q electrical characteristics.<br>
https://www.bourns.com/docs/product-datasheets/smcj-q.pdf

**S33 — Texas Instruments, LM74700-Q1 Datasheet**, Rev. G, Typical Application Schematic; Figure 3.<br>
https://www.ti.com/lit/ds/symlink/lm74700-q1.pdf

**S34 — Infineon, BSC065N06LS5 Datasheet**, Rev. 2.1 (2019-10-31).<br>
https://www.infineon.com/assets/row/public/documents/24/49/infineon-bsc065n06ls5-datasheet-en.pdf

**S35 — TE Connectivity, 1-776163-1 documents and drawings**, 35-position AMPSEAL header; drawing 776163; specification 114-16016.<br>
https://www.te.com/commerce/DocumentDelivery/DDEController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

**S36 — TE Connectivity, 776087-1 product page**, 23-position AMPSEAL header; drawing 776087; specification 114-16016.<br>
https://www.te.com/en/product-776087-1.html

**S37 — Texas Instruments, SN74AHCT541-Q1 product page**, automotive octal buffer/line driver.<br>
https://www.ti.com/product/SN74AHCT541-Q1

**S38 — Analog Devices, CN0415: Robust, Closed-Loop Control and Monitoring System for Solenoid Actuators**, Circuit Note, Rev. 0, sections “Circuit Function & Benefits”, “Circuit Description” and “Digital PID Control”.<br>
https://www.analog.com/en/resources/reference-designs/circuits-from-the-lab/cn0415.html#rd-description

**S39 — Analog Devices, CN0415 Circuit Note PDF**, Figures 1, 4, 12.<br>
https://www.analog.com/media/en/reference-design-documentation/reference-designs/cn0415.pdf

**S40 — Analog Devices, AN-105: Current Sense Circuit Collection**, Figure 122 “Monitor Solenoid Current on the Low Side”.<br>
https://www.analog.com/en/resources/app-notes/an-105fa.html

**S41 — Texas Instruments, TIDA-020023: Automotive proportional solenoid drive with highly accurate current sensor reference design**, reference design page, 1 kHz PWM.<br>
https://www.ti.com/tool/TIDA-020023

**S42 — Texas Instruments, TIDUEO6A: Automotive Proportional Solenoid Drive With Highly-Accurate Current Sensor**, Rev. A, §§ 2.3.3, 2.4.3, 2.4.4, 3.2, Figures 4, 6, 11–15.<br>
https://www.ti.com/lit/ug/tidueo6a/tidueo6a.pdf

**S43 — OpenPodcar/OpenPodcar**, public open-source vehicle project; README sections “Speed Potentiometer”, “Linear Actuator” and “DeadMan Handle (DMH) and Relay”; software GPL-2.0, hardware CERN-OHL-W.<br>
https://github.com/OpenPodcar/OpenPodcar

**S44 — OpenPodcar vehicle circuit diagram**, public hardware circuit diagram.<br>
https://github.com/OpenPodcar/OpenPodcar/blob/master/docs/hardware/OpenPodcar_Components_Circuit_Diagram_colored.pdf

**S45 — outlandnish/subaru-brz-vcu**, public vehicle-control design notes; README sections “Low side relay control”, “repurposed signals” and “Notes about power”.<br>
https://github.com/outlandnish/subaru-brz-vcu/blob/main/Readme.md

**S46 — darderik/relay_matrix_edsp**, MIT-licensed open-source relay matrix controller; README sections “4×4 crosspoint”, “TPL9201 drivers”, “exclusive switching commands” and “status query”.<br>
https://github.com/darderik/relay_matrix_edsp

**S47 — PrecisionMechatronicsLab/PneuSoRD**, MIT-licensed open-source pneumatic soft-robotics driver; README sections “Proportional 2x2 control”, “PWM/buck converter” and “Motor/Proportional Drive”; `PCB_PneuSoRD` hardware design files.<br>
https://github.com/PrecisionMechatronicsLab/PneuSoRD

**S48 — GormR/HW_for_AgOpenGPS**, open-source agricultural steering hardware; CERN-OHL-S-2.0; README, Level 2 hydraulic steering section.<br>
https://github.com/GormR/HW_for_AgOpenGPS/blob/main/README.md

**S49 — OpenHumidistat/hardware**, CERN Open Hardware Licence Version 2 — Strongly Reciprocal (CERN-OHL-S-2.0), `solenoid_driver` KiCad design files.<br>
https://github.com/OpenHumidistat/hardware
https://github.com/OpenHumidistat/hardware/blob/main/solenoid_driver/compact.kicad_sch

**S50 — Veldscholte & de Beer, “OpenHumidistat: Humidity-controlled experiments for everyone”**, HardwareX 11 (2022), e00288.<br>
https://pmc.ncbi.nlm.nih.gov/articles/PMC9058855/
https://doi.org/10.1016/j.ohx.2022.e00288

**S51 — Jinan Keya Electronic Science and Technology, Keya 12V/24V 50W 7Nm Tractor Autosteer Kit**, product page, Specification and Interface Definition sections.<br>
https://www.dcmotorkeya.com/Keya-12V-24V-50W-7Nm-Tractor-Autosteer-Kit-for-Agricultural-Machinery-Driverless-Steering-System-pd546247168.html<br>
Keya 转向电机演示视频（用户提供）：https://www.youtube.com/watch?v=uilSU-zbLFg

**S52 — SunNav, AG500Pro GNSS Auto-Steering System**, product page, High-Torque Motor Wheel specifications; Tractor Autopilot product overview.<br>
https://www.sunnavtech.com/ProductDetail.aspx?aid=434<br>
https://tractorautopilot.com/

**S53 — Smajayu, JY305 Tractor GNSS Auto-Steering System**, product page, system components and EMS2 Electric Motor sections.<br>
https://www.smajayu.com/product/jy305-tractor-gnss-auto-steering-system/

**S54 — rusEFI, Electronic Throttle Body**, project wiki, electronic throttle and pedal/throttle-position feedback overview.<br>
https://github.com/rusefi/rusefi/wiki/Electronic-Throttle-Body

**S55 — Open Vehicle Control System (OVCS)**, project README, Architecture Overview and OVCS1 full-size electric-vehicle conversion.<br>
https://github.com/open-vehicle-control-system/ovcs

**S56 — RetroPilot, Ocelot**, project README, Chimera raw VSS/CAN inputs and CAN-integrated Relay Core.<br>
https://github.com/RetroPilot/ocelot

**S57 — comma.ai, opendbc**, project README, vehicle-specific CAN definitions and car-port documentation.<br>
https://github.com/commaai/opendbc

**S58 — AutonomouStuff, PACMod3 ROS Driver**, project README, supported-system command topics including headlight, horn and hazard lights.<br>
https://github.com/astuff/pacmod3

**S59 — Mississippi State University ABE 6990 Autonomous Tractor course project, ROS 2 Autonomous Tractor**, project README, Overview and Actuator Control sections.<br>
https://github.com/sushant097/Ros2-Autonomous-Tractor

**S60 — Christopher Rome Terwelp, Remote Control of Hydraulic Equipment for Unexploded Ordnance Remediation**, Virginia Polytechnic Institute and State University, M.S. thesis, 2003-05-28; §5.1 Hydraulic System Conversion, §5.2 Electronic Modifications, Figures 5-3–5-6.<br>
https://vtechworks.lib.vt.edu/items/b871d558-08b3-47e1-bf6e-5911fc8d04db<br>
https://vtechworks.lib.vt.edu/bitstream/handle/10919/32306/Teleoperated_Excavator.pdf

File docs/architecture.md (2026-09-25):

# Architecture

[Project overview](../README.md) · [Hardware](hardware.md) · [Firmware](firmware.md)

Command and feedback paths

MMAI covers the boundary between an upper-level command source and the electrical
interfaces of an existing mobile machine. The controller may request steering,
propulsion, operating mode, or an auxiliary function. The machine interface
validates that request, decides whether it may take control, and maps it to the
available actuator connection. Feedback travels back through the interface.

## The three actuation paths

**Steering:** operate an electric steering actuator or another supported steering
input, then acquire the available angle, position, or actuator status. The H563
implementation includes a CAN steering-motor path; the physical mechanical
coupling remains specific to the machine.

**Propulsion:** translate a request into the input accepted by the existing drive.
One implementation controls the current through two proportional hydraulic-valve
coils. A different machine may expose an analog, relay, serial, or CAN drive input.
Valve current and vehicle speed are different quantities; the machine's hydraulic
response and feedback determine how one relates to the other.

**Auxiliaries:** operate relay contacts, discrete electrical signals, or a supported
CAN interface for functions such as lights, horn, or work equipment. Contact
selection, polarity, and coexistence with original switches are adapter choices.

## Commands and state

Keep the chain visible: receive a command, validate its framing and units, check
authority and enable conditions, apply machine mapping, then update the physical
output. In the other direction, sample an input, scale and validate it, record
its freshness, and encode the feedback. [Interfaces](interfaces.md) maps these
steps onto the existing source files.

The conceptual boundary is more general than the existing wire protocols. The
repository retains concrete protocols and machine mappings so their evolution
can be studied directly. A universal transport-neutral API is not assumed.

## Responsibility boundaries

| Layer | Responsibility |
| --- | --- |
| Upper-level controller | Decide intended motion or function; interpret returned state |
| Command/control policy | Validate requests, control authority, freshness, and mode transitions |
| Machine mapping | Interpret units, direction, output assignment, and machine interlocks |
| Electrical driver/input | Generate or acquire the actual voltage, current, contact, pulse, or bus message |
| Physical machine | Steering, propulsion, stored energy, original controls, and mechanical limits |

The H563 generation uses Secure and NonSecure firmware domains to separate
actuator ownership from network handling. This protected boundary is an
implementation choice. Other ports can use different MCUs or partitioning while
keeping command validation and physical output permission explicit.

Manual operation, command loss, emergency stop, and output defaults belong in the
machine design from the start. See [Safety](SAFETY.md) and the
[porting guide](porting-guide.md).

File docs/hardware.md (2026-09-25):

# Hardware reading guide

[Project overview](../README.md) · [Firmware](firmware.md)

The board sources show how a controller is connected to existing electrical
actuators and sensors. Read each revision together with its schematic, connector
assignments, and firmware; component ratings alone are not assembled-board ratings.

## H563 actuation ECU

Open [PROJECT1.kicad_pro](../pcb/roller/ecu/PROJECT1.kicad_pro). The
[root schematic](../pcb/roller/ecu/PROJECT1.kicad_sch) links the functional sheets:

| Sheet | Circuit function |
| --- | --- |
| [PAGE1](../pcb/roller/ecu/PAGE1.kicad_sch) | Supply conversion and indicators |
| [PAGE2](../pcb/roller/ecu/PAGE2.kicad_sch) | STM32H563, clocks, reset, debug, and security device |
| [PAGE3](../pcb/roller/ecu/PAGE3.kicad_sch) | Ethernet PHY and physical interface |
| [PAGE4](../pcb/roller/ecu/PAGE4.kicad_sch) | Two CAN physical interfaces |
| [PAGE5](../pcb/roller/ecu/PAGE5.kicad_sch) | Serial low-side relay-driver chain |
| [PAGE6](../pcb/roller/ecu/PAGE6.kicad_sch) | Relay contacts and relay-supply storage |
| [PAGE7](../pcb/roller/ecu/PAGE7.kicad_sch) | Two PWM valve-drive channels with current sensing |
| [PAGE8](../pcb/roller/ecu/PAGE8.kicad_sch) | Analog, temperature, isolated digital, and pulse inputs |
| [PAGE9](../pcb/roller/ecu/PAGE9.kicad_sch) | Power entry, reverse-current/polarity protection, and connectors |

The proportional-valve example uses low-side MOSFET switching, recirculation
paths, and current measurement. Firmware closes the coil-current loop. The
hydraulic circuit determines what the resulting valve current does to the machine.

The relay chain and contact matrix provide several ways to connect existing
signals. A contact may interrupt an original path, select a replacement signal,
or switch a load. Relay numbers alone do not define a portable machine function.

The [ECU source notes](../pcb/roller/ecu/README.md) retain circuit-source mappings
and related retrofit examples. The English overview and original Chinese notes
are linked there.

## Design revisions

Read the current `PROJECT1` schematic alongside earlier ECU revisions in the Git
history. Changes to connector assignments, output circuits, or input conditioning
need to be understood in the context of their matching firmware.
[Provenance](PROVENANCE.md) identifies retained ECU development milestones.

## Reading a design for a different machine

For each connector and output, identify the supply, reference ground, current
path, protection components, expected load, feedback, and reset state. Pay
particular attention to inductive energy, transient protection, fusing, grounding,
and manual-control coexistence. Resolve the actual symbol, footprint, and 3D model
used by the selected revision.

Voltage/current limits and environmental capability require revision-specific
evidence. Treat an estimate as a design target, and a component datasheet limit
as a component limit. This repository does not turn either into a certified
machine-level specification.

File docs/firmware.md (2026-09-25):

# Firmware reading guide

[Project overview](../README.md) · [Interfaces](interfaces.md)

The useful reading unit is a complete signal path. Start with a command or
feedback field, then follow its validation, state, mapping, and physical interface.
The source retains the structure of the actuation ECU implementation.

## H563 ECU

The [ECU project](../firmware/roller/ECU/) separates Secure actuator functions
from NonSecure network/application functions.

| Responsibility | Source entry point |
| --- | --- |
| Wire formats and parsing | [ecu_protocol.h](../firmware/roller/ECU/NonSecure/App/Inc/ecu_protocol.h), [ecu_protocol.c](../firmware/roller/ECU/NonSecure/App/Src/ecu_protocol.c) |
| Network receive and control arbitration | [ecu_network.c](../firmware/roller/ECU/NonSecure/App/Src/ecu_network.c), [control_authority_policy.h](../firmware/roller/ECU/NonSecure/App/Network/control_authority_policy.h) |
| Application loop and heartbeat | [ecu_app.c](../firmware/roller/ECU/NonSecure/App/Src/ecu_app.c) |
| Shared Secure/NonSecure interface | [safety_api.h](../firmware/roller/ECU/Secure_nsclib/safety_api.h) |
| Output enable, interlocks, and faults | [safety_service.c](../firmware/roller/ECU/Secure/App/Src/safety_service.c), [run_permit_policy.c](../firmware/roller/ECU/Secure/App/Src/run_permit_policy.c) |
| Proportional-valve current loop | [valve_control.c](../firmware/roller/ECU/Secure/App/Src/valve_control.c) |
| Steering command and CAN path | [steering_control.c](../firmware/roller/ECU/Secure/App/Src/steering_control.c), [steering_can.c](../firmware/roller/ECU/Secure/App/Src/steering_can.c) |
| Machine-state CAN acquisition | [vehicle_can.c](../firmware/roller/ECU/Secure/App/Src/vehicle_can.c), [vehicle_j1939.c](../firmware/roller/ECU/Secure/App/Src/vehicle_j1939.c) |
| State assembly and speed input | [ecu_data_model.c](../firmware/roller/ECU/NonSecure/App/Src/ecu_data_model.c), [speed_sensor.c](../firmware/roller/ECU/NonSecure/App/Src/speed_sensor.c) |
| Boot/update memory boundaries | [ecu_flash_layout.h](../firmware/roller/ECU/Shared/ecu_flash_layout.h), [OEMiROT project](../firmware/roller/ECU/Bootloader/OEMiROT/) |

For propulsion, follow the requested coil current through command validation,
Secure output permission, current control, and PWM compare values. Current
feedback closes this electrical loop; it does not by itself establish vehicle
speed or stopping distance.

For steering, distinguish requested angle/rate, the mode the implementation
accepts, actuator enable, and returned actuator state. For relays, trace the
semantic command to the actual contact wiring. Those mappings are machine-specific.

The implementation distinguishes automatic-output shutdown from manual run
permission. An emergency-stop transition can have different consequences from an
ordinary stale-command transition. Read the policy and state together before
borrowing an isolated function.

## Feedback and upper-level integration

Follow physical inputs through the
[state model](../firmware/roller/ECU/NonSecure/App/Src/ecu_data_model.c) and
[speed acquisition](../firmware/roller/ECU/NonSecure/App/Src/speed_sensor.c).
The upper-level controller must interpret validity, freshness, units, and faults
alongside the returned values. The [interface guide](interfaces.md) describes the
command/state boundary without assuming a particular host framework.

## Tools and historical context

The projects include CMake/CubeMX inputs, host utilities, and tests. They are
part of the engineering record, with assumptions tied to their original
hardware and development environment. Read a tool before using it, especially
if it can write flash, change device lifecycle, update firmware, or operate outputs.
An example command or a historical result is not a deployment procedure for a
different board.

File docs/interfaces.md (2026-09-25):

# Command, output, and feedback interfaces

[Architecture](architecture.md) · [Firmware source map](firmware.md)

MMAI describes a boundary, not a mandatory bus or wire format. A port should make
the following information explicit:

| Direction | Information | Mapping questions |
| --- | --- | --- |
| Upper layer to interface | Steering/propulsion request, auxiliary state, mode, enable, stop, heartbeat | What are the units, limits, freshness rule, and control authority? |
| Interface to machine | Relay/contact state, PWM/current, analog command, CAN or serial message | Which physical connection is affected, and what happens when control is lost? |
| Machine to interface | Position, speed, switch state, current, pressure, actuator or bus status | Is the measurement valid, fresh, scaled, and attributable to the intended input? |
| Interface to upper layer | Machine state, fault state, watchdog/enable state, interface health | Can the upper layer distinguish unknown state from a real zero? |

## H563 reference protocol

The source defines an Ethernet/UDP V2 frame with a 24-byte header, an `ECU2` magic
value, version/type, sizes, flags, sequence, timestamp, and CRC32C. The declarations
and serialization code are authoritative for the selected revision:
[header](../firmware/roller/ECU/NonSecure/App/Inc/ecu_protocol.h) and
[implementation](../firmware/roller/ECU/NonSecure/App/Src/ecu_protocol.c).

Message families include control commands, status/diagnostics, valve and steering
telemetry, valve configuration, and OTA transport. Existing control fields also
retain concrete machine functions. Separate those functions from the reusable
framing and validation logic when studying or adapting the protocol.

The V1/A5 compatibility format is distinct. It has its own framing, lengths,
units, and accepted operations; a legacy percentage command cannot be assumed
equivalent to a coil-current request. Use the actual parser and validation policy
instead of casting a host structure onto a network packet.

The shared [safety API](../firmware/roller/ECU/Secure_nsclib/safety_api.h) describes
the protected internal boundary. Numeric limits in that header are firmware
configuration choices, not guarantees of physical actuator capability.

## Machine adapters

The reference design's two CAN paths have different roles: machine-state
acquisition and steering-actuator control. Relay contact assignments, direction
mapping, scaling, and calibration belong to the machine integration. A public
CAN standard does not make a particular machine's command acceptance universal.

For another machine, document each function's command representation, physical
connection, feedback, neutral state, enable conditions, timeout behavior, and
manual-control interaction. Keep the mapping understandable as a table before
introducing abstraction in code.

## Upper-level integration

The host controller must implement the selected ECU wire contract, including
framing, units, state validity, and control freshness. Treat each protocol revision
as a specific interface contract rather than mixing message IDs or command units
across versions. Host frameworks remain outside the actuation-interface boundary.

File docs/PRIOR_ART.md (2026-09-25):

# Prior art and related systems

These references provide technical and historical context for electronic
interfaces to existing mobile machinery. The relevance notes describe connections
to MMAI's architecture; they do not imply identical implementations.

## Electronic and electrohydraulic machine control

**Hydraulic control system for a street sweeper — US4343060A.**
Donald L. Hildebrand and Ernest F. Prescott. Priority/filing: 1980-07-18;
publication: 1982-08-10. Describes speed sensing and electronic control of a
hydraulic pump's displacement to regulate sweeping mechanisms. It is an early
example of electrical feedback and hydraulic actuation on mobile machinery.
[Patent publication](https://patents.google.com/patent/US4343060A/en).

**Remote control modification for manually controlled hydraulic systems —
CA2019542C.** Louis G. St. Martin. Priority: 1989-06-28; application publication
CA2019542A1: 1990-12-28; granted publication CA2019542C: 2000-06-27. Describes
adding remote electrical/electrohydraulic actuation to a manually controlled
hydraulic steering system, including a parallel control path.
[Patent publication](https://patents.google.com/patent/CA2019542C/en).

## Electronic vehicle-control architectures

**Extending Technology to Drive By Wire Control — SAE Technical Paper 941191.**
Patrick Donoghue, Gregory Lee Larson, and Stephan Dondoe. Published 1994-04-01
according to the SAE catalog. Describes full-authority electronic drive control
within an integrated ground-vehicle electronics architecture, including feedback
and vehicle-dynamics control. DOI: `10.4271/941191`.
[SAE publication](https://saemobilus.sae.org/papers/extending-technology-drive-wire-control-941191).

**Driver control input device for drive-by-wire vehicle — US20040099468A1.**
Adrian Chernoff, Joseph Szczerba, and Julien Montousse. Priority/filing: 2002-11-26;
publication: 2004-05-27. Describes electrical driver-input signals and their use
with vehicle control and electromechanical/electrohydraulic actuators.
[Patent publication](https://patents.google.com/patent/US20040099468A1/en).

## Retrofit and vehicle-interface examples

**AIce — MRSD Project Team I, Carnegie Mellon University.** Project year: 2022.
The team's full-system account describes the transition through an RC car and
ATV to a drive-by-wire Zamboni. Its Zamboni description includes steering-shaft
motor actuation, a CAN throttle interface, an electrohydraulic braking path, and
ROS communication with an ECU. This is a concrete example of integrating
upper-level autonomy with distinct actuation interfaces.
[Project account](https://mrsdprojects.ri.cmu.edu/2022teami/implementation/full-system/).

**Otonos Vehicle Interface Controller — Applied Research Associates.**
Product documentation; publication date not stated, accessed 2026-09-24.
Describes translation of ROS/JAUS commands into vehicle-specific control and
feedback, direct CAN integration, and an optional controller for other digital,
analog, or manual-control interfaces.
[Manufacturer description](https://www.ara.com/otonos/products/).

## Circuit-level reference

**CN0415 Circuit Note — Analog Devices.** Reference identifier: CN0415;
landing-page publication date not stated, accessed 2026-09-24. Describes
proportional/two-state solenoid drive, PWM, current sensing, closed-loop control,
dither, and overcurrent protection. It helps explain the electrical functions
in a valve driver. Its high-side sensing arrangement differs from the low-side
shunt placement in the MMAI ECU example.
[Manufacturer circuit note](https://www.analog.com/en/resources/reference-designs/circuits-from-the-lab/cn0415.html).

The [ECU design notes](../pcb/roller/ecu/README.zh-CN.md) retain additional
component and system references associated with the schematic pages. A reference
supports only the specific circuit function or architecture it actually describes.

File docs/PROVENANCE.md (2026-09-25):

# Project provenance and development lineage

[Project overview](../README.md) · [Related engineering work](PRIOR_ART.md)

MMAI continues the mobile-machine interface work developed in the `mesondynamics`
repository lineage. Earlier work included street-sweeper development; this tree
documents the actuation ECU path for mobile machinery.
The recurring approach is to connect existing actuators and sensors through an
understandable electrical interface while keeping upper-level control separate.

## Source milestones

These are source-history markers. Dates are recorded Git author dates, and the
commit identifiers refer to this repository's history. A repository's initial
date does not imply that every later circuit or subsystem existed at that time.

| Date | Commit | Source milestone |
| --- | --- | --- |
| 2024-12-26 | `8027500` | Repository initialization and earlier engineering/template material |
| 2024-12-26 | `ef54d0d` | Initial repository/submodule setup |
| 2026-07-22 | `7406ac9` | ECU firmware organized under `firmware/roller/ECU` |
| 2026-07-29 | `03fa8d0` | ECU KiCad design introduced at `pcb/roller/ecu` |
| 2026-09-14 | `ac20bfa` | Abstract hardware project introduced |
| 2026-09-24 | `a8c1d1b` | Expanded documentation of retrofit paths and implementation choices |

For example, read a milestone with `git show 03fa8d0`, or follow the hardware
history with `git log --follow -- pcb/roller/ecu/PROJECT1.kicad_sch`. Earlier paths
can be inspected directly in the corresponding revision.

## ECU development and reusable ideas

The H563 ECU concentrates actuator control, electrical feedback, and a protected
firmware boundary in a dedicated interface controller. Retained revisions show
the development of its hardware and firmware.

The reusable ideas are command framing, validation, feedback acquisition, output
mapping, control freshness, and machine-specific interlocks. Relay assignments, actuator bus
messages, geometry, scaling, and calibration belong to a particular integration;
they should be distinguished from the general architecture.

## Attribution

The development history retains the author identities **Onicc**, **Yuan Mei**,
and **Chandra Tsai**. Existing source notices identify additional component
authors and licensors. Git authorship, circuit revision identifiers, and external
technical references serve different purposes; preserve each in its context.

The [hardware guide](hardware.md) and [firmware guide](firmware.md) connect these
milestones to the current source locations. Public technical precedents are
collected separately in [Prior art and related systems](PRIOR_ART.md).

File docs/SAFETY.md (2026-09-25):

# Safety

Mobile machinery can cause serious injury or death. This repository is
experimental engineering material and does not, by itself, constitute a
certified functional-safety system or establish suitability for road use.

Machine-specific hazard analysis and engineering review are needed before
changing steering, propulsion, braking, or original interlocks. The person
integrating the system must establish the appropriate physical protections and
operating procedures for that machine.

## Understand the complete stopping path

For every output, determine what occurs on reset, power loss, stale commands,
invalid input, communication failure, and emergency stop. An electrically
de-energized output is not automatically a safe mechanical state. Hydraulic
pressure, gravity, inertia, springs, and capacitors may retain energy after
power is removed.

A hardware emergency-stop path should not depend solely on application software
or network delivery. Its interaction with original manual controls, brakes, and
run permission needs an explicit machine-level design. A watchdog is one part
of that design, not a substitute for it.

## Explore at low energy

Use isolated signals, indicators, and suitable dummy loads to understand I/O
behavior before connecting machinery. Establish current limits, load protection,
grounding, and a means to remove energy. Progress from electrical observation to
one actuator at a time under controlled conditions, with an independent stop
available and people clear of motion.

Before relying on a port, exercise its command-loss, watchdog, output-disable,
manual-control, and fault-reset behavior on that installation. Previous code or
board evidence does not establish another machine's behavior. Example mappings
are not approval for unattended or safety-critical operation.

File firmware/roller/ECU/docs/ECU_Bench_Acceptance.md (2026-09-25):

# ECU 烧录与台架验收

当前新板 SN-EJAHGJQ 制造进度及未验收项目以
对应设备的制造记录为准；本文件历史实测属于
SN-EJAHGJI，不能自动作为新板验收结果。

固定地址为 SN-EJAHGJI：ECU `.11` / 域控 `.12`，SN-EJAHGJQ：ECU `.21` /
域控 `.22`（均为 `172.16.0.x`）。`ecu_network_acceptance.py`、
`ecu_valve_guarded_test.py`、`ecu_pi_compare.py` 用 `--device-serial` 显式选板；
新板必须指定 `--device-serial SN-EJAHGJQ`，可选 `--ecu-ip` 只能核对固定地址。
默认仍是旧板。错误映射拒绝启动，且所有主动客户端之前先做只读身份与
IDLE/K12-only/零输出门禁。新板的域控测试临时主机地址必须是 `.22`，不是 `.12`。

## 1. 安全前置条件

每次主动测试前逐项确认：

1. ECU 和车辆可靠固定，供电熔断/限流有效，实体急停可立即触及。
2. 车辆已支撑或行驶、启动、泵、振动、驻车等执行器已从危险能量链卸载；
   K12 失电确认为安全态。
3. 前进/后退阀允许在 200 mA 低目标下短时动作，两个方向切换不会造成机械运动。
4. 主机 UI、自动测试脚本和其他控制器不能同时占用控制权。
5. 只具备万用表/电流表时，不把 PWM 频率、开关瞬态、过冲和 EMC 判为已验证；
   这些项目必须在后续示波器和故障注入试验中补齐。
6. 转向主动测试前，车轮/铰接必须离地或与危险机械能量脱离，行程两端
   留有充足余量，人员离开夹挤区，并可立即切断电机供电。断电测量 J7-13
   `CAN2_H` 到 J7-16 `CAN2_L` 的总终端约为 60 Ω，然后才允许非零速度。

控制值归零时，普通接管继电器仍按活动控制帧维持；发送 RELEASE、关闭 UI 或等待
控制超时后，K1/K2/K5/K7/K9/K13 等自动接管继电器全部释放，但在认证、镜像、
实体急停和 Secure 关键边界健康时 **K12 人工驾驶许可保持闭合**。只有实体/网络
急停、OTA/factory 或 ATECC/SWI2C/TPIC/GTZC/internal 关键故障才硬断 K12。

## 2. 构建、审计与烧录

```sh
./tools/cubemx_cli.sh validate
./tools/audit_config.sh
./tools/test.sh
./tools/build.sh Debug
./tools/build.sh Release
./tools/build_oemirot.sh ReleaseOpen
./tools/build_oemirot.sh ReleaseClosed
./tools/build_signed_apps.sh Release
STM32_PROGRAMMER_CLI=/home/plac/.local/share/stm32cube/bundles/programmer/2.23.0/bin/STM32_Programmer_CLI \
  python3 tools/ecu_debug_auth.py --accept-closed-target discover
```

当前样件已从旧的直接 TrustZone 布局迁移为 OEMiROT，不能再用
`tools/program_ecu.sh flash` 覆盖 primary slot。日常升级使用 Ethernet：

```sh
python3 tools/ethernet_ota.py --status
python3 tools/ethernet_ota.py \
  artifacts/firmware/<version>/roller-ecu-<version>.recu
```

### 2.1 1.0.14 OPEN loader 替换历史门禁

当时的 1.0.14 OPEN loader 替换必须先离线运行：

```sh
./tools/provision_oemirot_open.sh preflight-open-oemirot-replacement
```

该命令不访问板卡。当时真正替换前 JP1 保持断开，ST-Link 必须接
SWD/GND/VTref/NRST；
使用 `replace-open-oemirot --accept-open-boot-replacement` 后，事务目录必须同时包含
fresh full Flash、128 KiB persistent、Option Bytes、runtime/OTA、两个 primary、
Programmer 直读 MCU UID、验签/完整身份/trailer 报告、固定的 ReleaseOpen 和
1.0.14 `.recu` 字节/hash，以及逐字节 boot readback。失败时只能
以错误消息给出的精确事务目录执行 `resume-open-oemirot-replacement`，不能复用旧
`repair-boot-layout` journal。

当时替换 loader 后先保持 ST-Link/NRST 接入，通过 Ethernet 安装并确认
1.0.14。板上原
1.0.12 应用尚未包含 LAN8742 冷启动复位时序修复，所以在 `accepted_sequence=14`、
双确认、runtime safe 和延迟复核完成前，严禁移除 ST-Link或执行掉电冷启动。首次
无探针冷启动必须发生在确认后的 1.0.14 上。

当前板和历史 CLOSED 验收阶段的 Option Bytes 必须满足：

```text
TZEN=0xB4
PRODUCT_STATE=0x72 (Closed)
BOOT_UBE=0xB4
SECBOOTADD=0xC0000, SECBOOT_LOCK=0xB4
SECWM1_STRT=0x00, SECWM1_END=0x7F
SECWM2_STRT=0x01, SECWM2_END=0x00
WRPSGn1=0xFFFFFFF0
WRPSGn2=0xFFFFFFFF
HDP1_STRT=0x00, HDP1_END=0x17
HDP2_STRT=0x01, HDP2_END=0x00
```

完整布局、首次 provision、JP1/BOOT0 阶段和 CLOSED 门槛见
`ECU_Security_and_OTA.md`。本样件曾完成 OPEN→CLOSED，随后因 Full Regression
回到 OPEN；现已通过 UUID=`0f3537fe-c04d-4298-ba50-995773e07a6a` 的不可变事务
再次进入 `0x72 CLOSED`。该 Full Regression→OPEN 过程仍作为历史恢复证据保留，
当前生命周期以安全文档第 6.3 节为准。

## 3. 本机 Ethernet

```sh
sudo ./tools/configure_ecu_network.sh
ip -brief address show enp2s0
ip route get 172.16.0.11
ping -c 3 172.16.0.11
./tools/check_ecu_latency.sh
```

预期主机 `172.16.0.10/16`、ECU `172.16.0.11/16`，路由直接从 enp2s0 发出。
脚本创建 NetworkManager 连接 `ecu-bench`，无 gateway/DNS/default route，并用
priority 100 路由规则避免 VPN 抢占 ECU 流量。恢复原连接：

延迟门槛默认是 100 包无丢包、平均 RTT≤1.0 ms、最大 RTT≤5.0 ms。固件使用
异步 Ethernet TX，状态/诊断不能阻塞 RX；1 kHz 阀样本按 8 ms 批量发送。空闲、
持续控制和遥测开启三种状态都必须分别通过，不能只测无业务空闲状态。

```sh
sudo nmcli connection down ecu-bench
sudo nmcli connection up 'Wired connection 1'
```

## 4. 自动 V2 功能验收

确认第 1 节全部成立、退出 UI 后执行：

```sh
./tools/ecu_bench_test.py --ecu-ip 172.16.0.11 --accept-unloaded-actuation
```

如果已经确认两个阀线圈均未接入，可使用下列显式降级模式继续验证继电器、目标
斜坡、PWM 互斥和换向状态机；该模式不会把电流闭环标记为通过：

```sh
./tools/ecu_bench_test.py --ecu-ip 172.16.0.11 \
  --accept-unloaded-actuation --accept-disconnected-valves
```

脚本通过 V2 UDP 50002 控制并从 50001/50003 回读，覆盖：

- 100 B 状态、86 B 诊断及 CRC-32C；
- 中性清故障、Secure ARM、K12 行车许可和固定接管 mask；
- K21/K17、K22/K23、K15/K16、K26/K27、K4/K6、K8/K10；
- K11 驻车、K13/K14 龟兔档、K18/K19；
- 无硬件兼容字段保持 no-op；
- 前进 200 mA 电流闭环、斜坡和 PWM 互斥；
- 从前进安全换向到后退 200 mA，另一方向 PWM 必须为零；
- K20 主动释放和 Secure 3 s 强制释放；
- K3 临时接管，K24(BAT/高) 或 K25(GND/低) 闭合 1 s，再恢复原车；
- `emergency_stop_request` 和 priority 255 紧急关断；
- sender 3 对 sender 1 的仲裁、超时回退、250 ms 后 IDLE/仅 K12 基线。

脚本失败或退出时主动发送 RELEASE；Secure 300 ms 超时独立归零所有自动输出，
但不把普通控制失联误当成车辆急停。诊断 mask 只证明软件要求的 TPIC 位，不证明
K12 或其他继电器触点、电磁阀和线束实际动作。

## 5. UI 电流调试与 DMM 验收

阀线圈位于 J6，当前原理图/PCB 的接线如下。必须断电接线，负端是 ECU 低边输出，
不能短接至 BAT 或外部 GND：

| 阀 | 线圈正端 | 线圈负端/ECU 低边 |
|---|---|---|
| 前进 `YV_FWD` | J6-26（+12 V） | J6-28 `YV_FWD_COIL_N` |
| 后退 `YV_BACK` | J6-27（+12 V） | J6-29 `YV_BACK_COIL_N` |

```sh
./tools/ecu_debug_ui.py --ecu-ip 172.16.0.11
```

打开 <http://127.0.0.1:8088>。推荐步骤：

1. 确认状态年龄 <300 ms，READY/ADC 有效，CALIBRATING 已消失，阀目标、反馈、
   占空比均为零；如有可清故障，保持中性后点击清除。
2. 进入“电流 PI 调参”，等待“波形就绪”且首批 1 kHz 基线样本已经显示，再读取
   ECU 参数；首次没有有效日志时应显示默认参数来源。
3. 在调参页启用零目标控制，依次给前进 `+100、+200、+300 mA`，每档至少保持
   2 s；用串联标准电流表测量线圈电流，并与 UI 前进反馈比较。每次阶跃必须从
   调参页直接设置，确认波形包含动作前基线；随后立即归零并确认反馈 <50 mA。
4. 依次给后退 `-100、-200、-300 mA` 并重复测量。不要直接从较大正值跳到较大
   负值；换向试验先用 ±200 mA，观察施加目标先降零且双 PWM 不重叠。
5. 每点记录：目标、稳态 DMM、ECU 反馈、占空比、供电电压、线圈温度。初始工程
   验收建议 `|ECU-DMM| ≤ max(50 mA, DMM读数×10%)`；生产指标必须由标定规范收紧。
6. PI 调节先限制最大占空比并从低电流开始。无示波器时只能依据 1 kHz 曲线评价
   毫秒级响应，不能排除 ADC/PWM 周期内振荡。优先小步调整 Kp，再调整 Ki 消除
   稳态误差；出现持续摆动立即目标归零并恢复已知参数。
7. “实时应用”只写 RAM。确认参数后先目标归零、等待反馈 <50 mA、点击释放控制，
   再“保存到 Flash”。保存成功后记录 active revision、generation 和 CRC。
8. 断电至少 10 s 后重上电，重新读取，参数和 generation 必须保持；然后再进行
   100 mA 低能量复验。这一步才构成掉电保存验收，ST-Link reset 不能替代断电。
9. 结束时目标归零、释放控制，确认 IDLE、requested/applied mask 仅含
   K12 bit22 (`0x00400000`)、两个 duty=0；若实体/网络急停或关键故障仍有效，则
   mask 必须为 0。

UI 波形包含请求目标、斜坡目标、带符号反馈、两路占空比，支持 CSV 导出。原始
文件应随测试编号、固件 commit、板号和仪表信息归档。

### 5.1 UI CAN2 转向分阶段验收

转向无本地角度反馈，必须把“通信零动作”与“低能量实动”分开记录。
第一阶段不勾选转向使能：

1. 确认 UI 每 100 ms 收到 52 B `STEERING_STATUS`，状态年龄 <500 ms，
   请求速度、已确认命令速度（非反馈）、速度命令千分比和电机速度反馈原始值为 0，
   `motor_enable_confirmed=0`。
2. 上电时 CAN 分析仪应看到先发 `0x2000=0`、再发 `0x200C=0`；禁止在
   启动序列中出现非零 `0x2000`。使能 `0x200D` 未收到严格 SDO ACK 时，
   状态不得进入 ACTIVE；节点 1 的厂商规定 ACK 是
   `ID=0x05800001, data=60 0D 20 00 00 00 00 00`，第 4 字节不是命令中的 1。
3. 分别在闲置、持续普通控制和打开 PI 波形三种情况执行
   `./tools/check_ecu_latency.sh`；均须满足无丢包、平均≤1 ms、最大≤5 ms，不得重现
   20 ms 级阻塞峰值。
4. 抓包确认 V2/V1 状态各为 20 Hz，转向/诊断/安全状态各为 10 Hz，周期类报文按
   0/10/25/35/60 ms 相位分散，同一 HAL 毫秒最多提交一类周期应用帧；调参未打开时
   UDP 50004 必须没有高速遥测。
5. 分别从遥控器 `172.16.0.9`、调试机 `172.16.0.10`、SN-EJAHGJI 域控
   `172.16.0.12` 使用不同 sender 发送全中性控制，再以不同的 1..254 priority
   逐级竞争；确认数值较大的活动 sender 获得控制，相同数值由较小 sender ID
   确定性胜出，低优先级 sender 继续续租但不会影响当前输出。当前活动控制方超过
   250 ms 后按既有 IDLE/Disarm/rearm 边界处理。
6. 从 `.9` 和 `.12` 发送 GET/APPLY/SUBSCRIBE/OTA STATUS，确认 ECU 不回复；只有
   `.10` 可使用调参、遥测和 OTA。从未列入白名单的受控测试地址发送普通控制，
   确认 ECU 不动作；再发送结构及校验正确的零输出急停，确认其仍进入安全停止。
   该项只验证纵深 IP 策略，不得记录为密码学鉴权测试。
7. 在每个白名单 IP 上用第二个受控测试进程和不同 UDP 源端口发送更新 sequence，
   记录同一 IP 属于一个主机信任域而可接管相同 sender；同时确认不同 IP 不能续租
   已绑定 sender。生产主机进程隔离和点对点二层隔离必须纳入系统验收，不能把
   源端口、源 IP 或 CRC 当作密码学身份认证。
8. 从 `.12` 断言网络急停，确认 bit28 锁存、K12/自动输出立即为零；停止发送并等待
   300 ms，再分别发送普通中性、RELEASE 和 CLEAR_FAULT，bit28 必须仍保持。随后
   从 `.9` 先建立全中性禁用绑定，再发送唯一 flag bit3 的严格更新 sequence
   `ESTOP_RESET`；确认 bit28 清除，PB2 连续健康 20 ms 后只恢复 K12，reset 会话
   已销毁且所有普通 sender 仍须新会话/中性 rearm。最后让 `.9` 与 `.12` 同时持续
   断言，确认任一紧急 sender 仍存活时 reset 被拒绝。

只有本文第 1 节与转向附加安全条件均已由现场人员确认，才进入第二阶段：

1. 将 UI sender 设为 1 或 2，输入小速度（建议首次 0.6°/s，换算后约为 1‰
   额定转速命令），勾选转向使能并确认风险对话；保持不按方向键，确认使能
   ACK 后速度命令仍为 0。电机参数 0002 必须先核对为 80 rpm；否则禁止实动。
   断开或屏蔽 ACK 时，ARM 必须在 750 ms 内自动失能；已确认后即使保持零速度，
   丢失 ACTIVE/command-enable/motor-enable 任一确认也必须自动失能。
2. 点按正向不超过 200 ms 后松开，确认方向与整车定义一致、松手立即回零；
   反向重复。若方向错误，立即停止并修正受版本控制的方向配置，不得靠现场记忆补偿。
3. 按住某方向不松，确认 2 s 到期后自动零速度/禁用、置位
   `MANUAL_LIMIT|REARM_REQUIRED`，且持续非零包不能重启；必须先 STOP 才能再次 ARM。
4. 在零速度下测试页面失焦、切换 sender、断开上位端网络和 CAN 节点掉线；
   分别确认零速度/禁用序列、250/300 ms 双看门狗、bus-off/timeout 故障可见，
   且转向局部故障不破坏 Ethernet、CAN1 和无关继电器的调度。
   另用 251 ms、299 ms 周期发送同一 sender 的非零包，确认控制权仍在过期瞬间
   IDLE/Disarm，非零帧被拒绝；只有全中性禁用帧、完整 20 ms 安全轮和 Secure
   接受后才能重新 ARM。反复每 1 ms 请求安全或每 20 ms发送 disable-zero 时，
   延迟 45 ms 的零速/禁用 SDO ACK 仍必须完成原事务，不能被刷新丢弃。
5. 结束后点击 STOP、取消使能、释放控制，确认零速度、电机未使能、
   控制模式 IDLE，并归档 CAN 抓包、UI 截图、延迟报告和固件 hash。

## 6. 参数存储专项测试

| 测试 | 操作 | 通过标准 |
|---|---|---|
| RAM-01 | 修改一个 Kp 后 APPLY，不 SAVE，复位 | 参数恢复为 Flash 值 |
| NVM-01 | APPLY 后 RELEASE/SAVE，断电重启 | 新参数和 generation 保持，CRC 有效 |
| NVM-02 | 控制有效或电流未归零时 SAVE | 返回 BUSY，不执行擦写 |
| NVM-03 | 10 s 内重复写不同参数 | 第二次返回 RATE_LIMITED |
| NVM-04 | 连续写满单扇区并跨扇区 | 最新 generation 有效，上一扇区掉电备份仍可扫描 |
| NVM-05 | 在记录提交前掉电（开发样件） | 未 commit 记录被忽略，恢复上一个有效记录 |
| FW-01 | 保存参数后执行普通 `flash` | 烧录前后参数区字节一致，重启仍加载原参数 |

NVM-04/05 会反复擦写或故意断电，只能在开发样件和受控供电夹具上执行，不能在
车辆运行状态进行。

## 7. 仍需仪器或外部信号的验证

| 编号 | 项目 | 通过标准 |
|---|---|---|
| HW-01 | 实体急停 | 按下时 K12/TPIC/PWM 立即全关并锁存；释放连续健康 20 ms 后只恢复 K12，不自动 ARM；CLEAR_FAULT+中性 rearm 后才允许自动输出 |
| HW-02 | TPIC 位序/触点 | 每 bit 与 K1..K27 一致，保留位不动作，失电回到安全触点 |
| HW-03 | K20 启动 | 示波器确认连续高电平不超过 3 s |
| HW-04 | K3/K24/K25 | K3 先 50 ms；K24 或 K25 1 s 且互斥；源先释放，50 ms 后 K3 恢复 |
| HW-05 | PWM/ADC 同步 | 20 kHz 中心对齐；ADC 在导通脉冲中心采样；换向无重叠脉冲 |
| HW-06 | 阀故障注入 | 过流、开路、反馈轨故障、非活动电流均锁存并归零全部自动输出；若 Secure 关键边界及急停健康，K12 保持人工驾驶许可 |
| HW-07 | 速度 PA0 | 20000 pulse/km 换算正确，1500 ms 后信号丢失 |
| HW-08 | 慢 ADC | 各通道顺序、电压换算、开短路行为符合传感器规范 |
| HW-09 | Secure CAN1/J1939 | 250 kbit/s 六 PGN 解析与旧车一致，1000 ms 有效/1001 ms 过期，非法格式/其他 ID 拒绝；NonSecure 仅见 NSC 快照；warning/passive/bus-off 置 bit27，恢复后清除且不影响 Ethernet/CAN2 |
| HW-10 | CAN2 转向 | 250 kbit/s；只接收节点 1 SDO/heartbeat；零速度/禁用先行；使能 ACK 前无非零 TX；正反向短脉冲、手动 2 s 限时和通信故障安全停机全部通过 |
| HW-11 | PB8/PB9 软件 I²C/ATECC reset recovery | PB9=SCL、PB8=SDA；启动无条件 START+9 clocks+START+STOP，随后 reset/sleep；最长 725 ms 有界重试期间服务 IWDG；当前 R1 无飞线 |
| HW-12 | IWDG/CSS | NonSecure 停止或 HSE 故障时先关输出，约 2 s 复位 |
| HW-13 | 电源/EMC/热/耐久 | 无非预期吸合，等级符合整机风险分析和目标标准 |
| HW-14 | 网络急停锁存/解除 | `.9/.10/.12` 任一源可断言；断链、超时、普通中性、RELEASE、CLEAR_FAULT 均不能解除；独立全中性 ESTOP_RESET 后 PB2 健康 20 ms 只恢复 K12，重新控制须新会话和中性 rearm |

该固件的故障安全设计不能替代独立硬件安全链，也不构成 IEC 61508、ISO 13849
或整车功能安全认证。

## 8. 成对 OTA 故障与断电验收矩阵

验证层级定义如下：`HOST` 是静态源代码/派生 loader 审计或本机单元测试；
`HW` 是目标 ECU、Ethernet 和受控电源上的实板项目；`HW-FI` 是必须使用专用
故障注入固件或夹具执行的项目。HOST 通过只能证明策略和构建产物结构，不能替代
真实 Flash、复位、IWDG 和掉电时序证据。

量产板逐板进入 CLOSED 前的本板门禁是 OTA-H01..H07、OTA-P01 正常安装、两个
primary 的独立验签/完整身份/双确认审计，以及 JP1 断开、完全移除 ST-Link 后的
仅 ECU 冷启动、ATECC/安全基线和 Ethernet 延迟复核。OTA-P02..P17 是绑定硬件版本、
loader 源码与发布 hash 的**发布/型式鉴定矩阵**，只在具备完整恢复能力的专用 OPEN
样件或可替换 Flash 夹具上执行；它们不是每块量产 ECU 在 CLOSED 前重复承受的测试。

### 8.1 静态与主机门禁

| 编号 | 检查/命令 | 通过标准 | 层级 |
|---|---|---|---|
| OTA-H01 | `./tools/test.sh` 的 paired policy 测试 | PERM、TEST/REVERT 冲突拒绝；`NONE/TEST`、`NONE/REVERT` 与完整发布身份比较的状态枚举符合设计 | HOST |
| OTA-H02 | `./tools/test.sh` 的 confirmation policy 测试 | 穷举两侧 `image_ok` 字节，只有精确的 `0x01/0x01` 可提交硬件 counter | HOST |
| OTA-H03 | `./tools/build_oemirot.sh ReleaseOpen` 和 `ReleaseClosed` | 实际生成 loader 的顺序严格为 partial-PERM guard → recovery review/complete → initial counter gate → dependency → target-pair gate → swap → primary validation → final-pair gate → redundant countermeasure | HOST |
| OTA-H04 | `./tools/audit_config.sh` | clean/partial PERM、双 counter 提交谓词、最终身份门、FIH 判定、双 controller relock-or-reset 和 gate 顺序锚点均存在 | HOST |
| OTA-H05 | `python3 -m unittest discover -s tests -p 'test_package_firmware.py' -v` | version/counter 不可重用，发布历史不完整时 fail closed，已进入发布历史的 1.0.13 身份不能被重用 | HOST |
| OTA-H06 | `./tools/test.sh` 后构建两个 OEMiROT profile | trusted-pair 谓词拒绝未确认/半确认、单侧未验签或身份不一致；派生 loader 中 FIH 授权默认失败，只能在完整提交门后打开，且 FAIL guard 严格早于 `swap_set_image_ok()` | HOST |
| OTA-H07 | `test_ota_physical_estop_source.py`、Secure source audit 和主机包校验 | BEGIN/每个 CHUNK/FINISH/未确认镜像确认都要求实体急停；主机收到新鲜 PB2 急停诊断后才开始，并在报告完成前核对目标 sequence、1.0.20 锁存急停 capability、ATECC auth、无 OTA 状态且 K12 命令为断 | HOST |

### 8.2 发布/型式鉴定硬件矩阵

| 编号 | 故障或断电注入点 | 通过标准 | 层级 |
|---|---|---|---|
| OTA-P01 | 正常安装 1.0.15 或更高的同身份 TEST 配对 | 两侧验签并启动同一 version/counter；NS 后 S 精确写入 `image_ok=0x01`；只有双确认后硬件 counter 才推进，冷启动保持新配对 | HW |
| OTA-P02 | CHUNK 期间多点断电，包括仅一侧完整 secondary 已带 TEST trailer、另一侧尚不完整 | 依赖检查先取消不完整请求，旧的已确认 S/NS 配对启动；目标门不误拒绝可恢复旧配对，应用绝不接收 old/new 混合 primary | HW |
| OTA-P03 | FINISH 后及两侧 forward swap 的每个可控阶段断电 | OEMiROT 续做到完整新配对或恢复完整旧配对；每次应用入口处两个 primary 的完整 version/counter 必须相同 | HW |
| OTA-P04 | 未确认镜像启动时分别断开网线、制造短暂 MDIO 读错和持续 PHY/时钟故障 | 仅 link-down 不阻止地址 0/PHY ID 就绪与确认；短暂故障可在 5 s 内恢复；持续故障在 5 s 内停止喂狗并成对回滚 | HW |
| OTA-P05 | 在写 NonSecure `image_ok` 之前断电 | 两侧仍未确认，下一次启动成对回滚；两个硬件 counter 均不推进 | HW |
| OTA-P06 | NonSecure `image_ok=0x01` 后、Secure flag 写入前断电 | 相同发布身份的半确认被派生 loader 识别为 `NONE/REVERT`，验证旧 secondary 后强制双回滚；两个硬件 counter 均不推进 | HW |
| OTA-P07 | 双回滚已完成一侧、另一侧尚未完成时多点断电 | primary 身份不同被识别为回滚续做，只完成剩余一侧；最终为完整旧配对，混合配对从不进入应用 | HW |
| OTA-P08 | 两侧 `image_ok=0x01` 后，在两个硬件 counter 依次更新及其复位边界断电 | 不回滚已确认新配对；每次复位仍先验证双 flag/header，安全地续做尚未推进的一侧 counter | HW |
| OTA-P09 | 用受控测试密钥构造签名均有效但 version 或 protected counter 不同的 S/NS 目标，并覆盖剩余 secondary 不可读/损坏路径 | post-dependency 目标门或最终 primary 完整身份门以 `BOOT_EBADIMAGE` 停止；任何混合 primary 均不跳转应用 | HW-FI |
| OTA-P10 | 注入 `BOOT_FLAG_BAD`、无效 header 和非 `0xFF/0x01` flag | 确认、counter 与应用启动均 fail closed，不把异常值解释为已确认 | HW-FI |
| OTA-P11 | 分别强制 `HAL_FLASH_Lock_S()`、`HAL_FLASH_Lock_NS()` 失败 | 在返回 NonSecure 应用前立即执行系统复位；复位后 controller 为锁定态，OEMiROT 按实际双/半确认状态处理 | HW-FI |
| OTA-P12 | 对已确认镜像制造持续 PHY/REFCLKO 故障，再恢复或受控复位 | 安全主循环持续运行、输出保持安全且网口保持 down，不因 5 s test-swap 门禁自动回滚或复位；硬故障仅由受控 MCU 复位/整机掉电恢复 | HW |
| OTA-P13 | 分别在 Secure 或 NonSecure PERM swap 的各恢复阶段断电，形成单侧 partial PERM | `boot_prepare_image_for_update()` 在 review/complete 和任何新恢复写入前 FIH fail closed；partial 状态不被擦除为 `NONE`，应用和 NV counter 更新均不可达 | HW-FI |
| OTA-P14 | 构造两侧 interrupted PERM，并组合双 `image_ok=0x01`、单侧/双侧有效签名尝试绕过确认 | 无论先处理哪一侧，partial-PERM guard 都先于恢复与 counter 路径拒绝；两个 NV counter 均不改变，任何镜像组合均不跳转应用 | HW-FI |
| OTA-P15 | 安装尚未确认的同身份 TEST pair，再破坏两个 rollback secondary，使两侧均进入 `BOOT_SWAP_TYPE_FAIL` | FIH trusted-pair 授权保持失败；在任一 `swap_set_image_ok()` 前 fail closed，两个 primary flag 保持原未确认值，两个 NV counter 不变且应用不启动 | HW-FI |
| OTA-P16 | 以已双确认、当次双侧完整验签且身份一致的 primary pair，注入单侧及双侧坏 staging/FAIL | 只有该 trusted pair 允许幂等 FAIL 清理；flag 保持 `0x01`、发布身份和 NV counter 不被伪造或意外改变，最终仍只启动同一 trusted pair | HW-FI |
| OTA-P17 | 正常 OTA 全程人工持续按住实体急停；分别在 BEGIN 前、CHUNK、FINISH 后/reset、确认前尝试释放 | 未按下时 BEGIN 拒绝；传输中释放使后续 CHUNK/FINISH 拒绝；未确认镜像在 PB2 释放时不写 image_ok 并由 IWDG 回滚；正常保持时主机只在 accepted sequence、能力、ATECC、无 OTA 状态和 K12 断开均确认后提示可释放 | HW |

OTA-P01 必须在待转换板或 CLOSED 后唯一发布形成独立实测记录；第 10 节历史
OTA PASS 不能替代第 11.2 节的 1.0.15 转换基线、第 11.3 节的 1.0.16
完整终验或第 11.4 节的 1.0.17 CLOSED Ethernet OTA。第 11.1 节的 1.0.14 三次无探针
冷启动保留为历史证据，不能冒充当前发布。OTA-P02..P17 的发布/型式鉴定记录
必须精确绑定固件包 SHA-256、S/NS version/counter、update sequence、loader 源码和
硬件版本；相关断电记录还应包含注入时刻、掉电保持时间、重启后的
swap/flag/counter、零输出和网络状态。已批准且绑定相同发布基线的型式试验证据可供
该批量产板 CLOSED 评审引用，不在每块生产板上重做破坏性注入。

不得刷写已撤销的 1.0.13、1.0.18 或 1.0.19，也不得为了补测而复用已经接受的
1.0.14、1.0.15、1.0.16、1.0.17，或已经签发后撤销的 1.0.18/1.0.19 identity；尚未
完成的 OTA-P02..P17 必须在下一唯一发布身份或专用测试发布上执行，并明确记录为
PENDING，不能写成 PASS。OTA-P15/P16 会故意破坏 rollback/staging，只能使用具备
完整恢复包的 OPEN 专用样件或可替换 Flash 夹具执行，不得在生产 ECU、唯一验收板
或 CLOSED 样件上试验。

## 9. 2026-08-27 功能实测记录（历史）

测试对象为 STM32H563（Device ID `0x484`），ST-Link 序列号
`066BFF565456857187210935`，调试固件从本工作区构建并烧录。结果如下：

| 项目 | 实测结果 | 结论 |
|---|---|---|
| CubeMX/代码 | CubeMX 6.18 隔离目录实际生成后，配置审计、7 项协议测试及 Debug 构建通过；最终 Debug/Release 构建通过 | PASS |
| 普通固件升级 | Secure/NonSecure 下载及 verify 成功；`0x080FA000..0x080FDFFF` 升级前后逐字节一致 | PASS |
| Ethernet 空闲 | 100 包，0% 丢包，RTT min/avg/max=`0.071/0.122/0.329 ms` | PASS |
| Ethernet + 1 kHz 遥测 | 100 包，0% 丢包，RTT min/avg/max=`0.086/0.126/0.265 ms`，会话丢样=0 | PASS |
| 完整动作后 Ethernet | 100 包，0% 丢包，RTT min/avg/max=`0.082/0.128/0.312 ms` | PASS |
| 参数 RAM/Flash | 默认参数 APPLY 成功；SAVE generation=1、CRC32C=`0xACD6FCBE`；ST-Link 硬复位及断电至少 10 s 后均完整读回 | PASS |
| V2/继电器/安全逻辑 | 自动脚本 29 项通过；结束后 IDLE、relay mask=0、两路 duty=0、故障=0 | PASS |
| 前/后阀无负载输出 | ±200 mA 目标斜坡、占空比约 596‰、PWM 互斥及安全换向通过 | PASS |
| 前/后阀真实电流闭环 | 当前反馈仅 0–1 mA，确认台架未形成线圈电流回路 | BLOCKED：接入线圈后执行第 5 节 |

本记录没有把诊断 relay mask 当作触点电气验证。10 s 真实掉电后的参数保持已经
通过；连接阀线圈并串联电流表完成电流闭环标定后，才能关闭剩余的阀带载验收。

## 10. 2026-08-29 安全启动与 OTA 实测记录（历史）

下表记录同一开发样件执行 Full Regression 之前的状态：当时已安装去除临时启动
trace 的 `ReleaseClosed` OEMiROT，JP1 断开，产品状态为 CLOSED (`0x72`)；最终
运行版本为 `1.0.9`，security counter=9，update sequence=9。它不是当前生命周期
状态，也不是第 8 节新增成对策略的 HW/HW-FI 验收证据。

| 项目 | 实测结果 | 结论 |
|---|---|---|
| ATECC608C | serial=`0123d47eb2ee0e9bee`，revision=`00006005`，config CRC32C=`0xEBB326F3`，Config/Data/slot 2 locked，P-256 随机挑战通过 | PASS |
| MCU 配对 | OPEN 阶段 Programmer 物理 UID=`003800613434511232383537`；OEMiROT 使用固定且已复核的 RSS IDCODE/SFSP manifest，handoff 带反码和 CRC32C，不依赖不可用的实时 DBGMCU 读取；HUK 封装 OBKeys、ATECC 不可导出私钥及 CLOSED/HDP 配对记录构成防移植根，pairing generation=1 | PASS |
| 主机测试/审计 | 9 项协议测试、完整配置审计、CubeMX 6.18 `.ioc` 加载校验、`git diff --check`、签名应用和 ReleaseClosed 构建通过 | PASS |
| CLOSED Ethernet OTA | `1.0.8`→`1.0.9` 成对 Secure 192 KiB + NonSecure 320 KiB 下载、FINISH、签名/哈希验证、test swap、应用确认成功；全程未使用 ST-Link | PASS |
| 中断/提交边界 | 65536 B 中断的无效 incomplete image 不启动；完整 signed secondary 自带 trailer magic，未 FINISH 后复位仍可能被 OEMiROT 评估，因此生产流程强制 FINISH 并核对 journal | PASS（边界已修正文档） |
| 传输签名 | 篡改包拒绝，result=-16 | PASS |
| 防重放 | 已接受 sequence 后再次发送同包，BEGIN 拒绝，result=-19；schema-2 journal 最终 quadword 带反码及 generation/sequence 副本 | PASS |
| OEMiROT 防回滚 | 较低 security counter 的签名包可完成传输但不替换已确认 primary | PASS |
| Flash 写后校验 | 定位并修复 STM32H5 ICACHE 对刚擦写 journal 返回旧值；OTA、身份、阀参数存储均在回读前失效 cache | PASS |
| 最终冷启动状态 | ota_result=0、state=IDLE、accepted_sequence=9；ATECC auth=0；relay mask=0、两路 duty=0、调参未启用、遥测发送计数=0 | PASS |
| 最终 Ethernet | 冷启动 10 包 0% 丢包，RTT min/avg/max=`0.078/0.140/0.186 ms`；100 包门禁=`0.058/0.129/0.185 ms` | PASS |
| DA 售后调试 | 三证书链+leaf 私钥成功临时打开 HDPL3 S/NS；Secure/NonSecure primary 可读；close-debug 成功 | PASS |
| Full Regression 能力 | DA permission `0x4040` 含 bit14；工具要求 `--accept-full-device-erase`，未在本样件执行以免擦除全部 Flash/OBKeys | PASS（非破坏性验证） |
| ST-Link 防导出 | close-debug 后普通 Hotplug AP1 连接和 `0x0C030400` 读取均被拒绝 | PASS |

固件包 `artifacts/firmware/1.0.9/roller-ecu-1.0.9.recu` 的 SHA-256 为
`c2c18673e6d370462bb64abc5dcdd3f8443813205ca5ef050a9af7bf4cbd335e`。离线 PKI
双备份已由密钥负责人确认；本记录不包含破坏性的 Full Regression 实跑。

## 11. 2026-08-30 OPEN→CLOSED 样件回归记录

本节只记录已取得的实测证据。当前产品状态为 CLOSED (`0x72`)，已接受唯一签名的
1.0.17/counter17/`accepted_sequence=17`，JP1 断开。1.0.15 的不可变 CLOSED
转换、普通未认证读取拒绝与 DA 售后边界继续作为转换/恢复基线；1.0.16 的发布后
DA 回读、关闭调试和最终无探针冷启动也已独立完成。1.0.17 的 DA 精确回读、
关闭调试、关闭后读取拒绝和最终无探针冷启动均已完成。

### 11.1 1.0.14 OPEN loader 替换与无探针冷启动历史证据

| 项目 | 2026-08-30 实测结果 | 结论 |
|---|---|---|
| OPEN loader 替换 | 不可变事务 `stm32h563-066BFF565456857187210935-20260830T050808Z-open-loader-replacement` 达到 `replacement_complete_stlink_cold_start_embargo_active`；ReleaseOpen 52276 bytes、SHA-256=`5fdaaa3f5e2d2a6c01ed527282ba08b3d8d5e579c61ec3c4e097cdf2c0fd7761`，写后逐字节回读一致并恢复 WRP/HDP | PASS |
| Ethernet OTA 1.0.14 | 使用事务内固定包 SHA-256=`a052f51a7ef14bbbec57f412950edad7f44f92a2323227d74c606d8dd866324d` 完成成对 TEST swap；最终 `state=IDLE`、`result=0`、`ota_result=0`、`accepted_sequence=14` | PASS |
| primary 密码学审计 | Secure/NonSecure 分别用各自 OEMiROT 公钥验签；完整 identity 均为 `1.0.14+0`/counter14，trailer magic 合法且 `image_ok=0x01/0x01` | PASS |
| V2 无负载回归 | 在明确两路阀线圈未接入的模式下 29/29 项通过；继电器逻辑、200 mA 目标斜坡、PWM 互斥、安全换向、仲裁和超时释放通过，结束后 IDLE/relay mask=0/duty=0 | PASS（真实阀电流跟踪 SKIP） |
| 替换前基线延迟 | 100 包 0% 丢包，RTT min/avg/max/mdev=`0.059/0.116/0.190/0.025 ms` | PASS |
| OTA 后空闲延迟 | 100 包 0% 丢包，RTT min/avg/max/mdev=`0.057/0.128/0.183/0.033 ms` | PASS |
| 29 项动作后空闲延迟 | 100 包 0% 丢包，RTT min/avg/max/mdev=`0.057/0.133/0.186/0.034 ms` | PASS |
| PI 调参遥测延迟 | 仅在调参会话中启动 1 kHz 遥测时，100 包 0% 丢包，RTT min/avg/max/mdev=`0.063/0.129/0.185/0.030 ms`；退出后 telemetry frames=406、dropped samples=0，遥测已停止 | PASS |
| 无探针冷启动 | 连续三次保持 JP1 断开、完整移除 ST-Link，并在 ECU 断电至少 10 s 后仅 ECU 上电；每次均通过 fresh MCU/ATECC 身份、`accepted_sequence=14`、OTA IDLE/result=0、双确认和零输出门禁 | PASS |
| 冷启动周期 1 延迟 | 100 包 0% 丢包，RTT min/avg/max/mdev=`0.051/0.118/0.192/0.036 ms` | PASS |
| 冷启动周期 2 延迟 | 100 包 0% 丢包，RTT min/avg/max/mdev=`0.063/0.123/0.247/0.040 ms` | PASS |
| 冷启动周期 3 延迟 | 100 包 0% 丢包，RTT min/avg/max/mdev=`0.064/0.143/0.194/0.028 ms` | PASS |

以上 1.0.14 结果保持原始版本、counter、sequence 和 RTT，不回填为当前发布。

### 11.2 1.0.15 CLOSED 转换与恢复基线

| 项目 | 2026-08-30 实测结果 | 结论 |
|---|---|---|
| Ethernet OTA 1.0.15 | package SHA-256=`9980acbf248f242c77c7044f48d627ca862d6714221f5835c0a21b7a24bf9e54`；成对 TEST swap 和确认完成，最终 `state=IDLE/result=0/ota_result=0/accepted_sequence=15` | PASS |
| installed primary fresh audit | Secure/NonSecure 均为 `1.0.15+0`/counter15，精确匹配 reviewed header、TLV、解密后 plaintext payload 与两次 swap trailer，`image_ok=0x01/0x01` | PASS |
| ATECC MCU-only hostile reset | 每轮依次执行 option-byte display/reset、under-reset UID read、final reset，ATECC 全程不断电；20/20 周期均通过 fresh 配对认证、accepted15、零输出和 Ethernet，证据为 `artifacts/hardware-regression/20260830T061938Z-atecc-reset-recovery/` | PASS |
| ATECC 有界恢复策略 | 启动无条件执行 `START + 9 clocks + START + STOP`，再执行 word-address reset/sleep；以 25 ms 步长、最长 725 ms 重试并服务约 2 s IWDG，超时保持 quarantine | PASS |
| Pairing A/B repair | A=`0x080E0000` 原 committed record 保持不变；B=`0x080E2000` 从全擦除修复为同一 generation-1 record，写后逐字节回读；A/B 字节一致，16 KiB SHA-256=`45f1f08b626f3934f2359e4d44b1993c9333c5275f62870d74a77caeb6c9f310` | PASS |
| CLOSED dual pairing gate | 事务 `artifacts/device-backups/stm32h563-066BFF565456857187210935-20260830T063129Z-closed-transition/`，UUID=`0f3537fe-c04d-4298-ba50-995773e07a6a`；finalizer 从 fresh full Flash 与独立 persistent readback 得到同一 16 KiB store，dual verifier 校验 A/B 后先持久化 `pairing_store_dual_verified`，再进入 `pre_mutation_evidence_verified` 和首次写操作；最终 phase=`product_state_closed_verified` | PASS |
| V2 基线无负载回归 | 1.0.15 上 29/29 通过，结束后 IDLE/relay mask=0/duty=0 | PASS（真实阀线圈 SKIP） |
| PI telemetry gating | frames=`0 → 175 → 175`，只在调参 session 内增长，退出后保持 175；dropped samples=0 | PASS |
| PI 调参网络延迟 | 调参开启时 100 包 0% 丢包，RTT min/avg/max=`0.059/0.114/0.290 ms` | PASS |
| 退出调参后空闲延迟 | 100 包 0% 丢包，RTT min/avg/max=`0.059/0.127/0.185 ms` | PASS |
| Full Regression recovery | `artifacts/device-backups/stm32h563-066BFF565456857187210935-20260830T064244Z-final-1.0.15/`，schema v4，exact 1.0.15，绑定同一 CLOSED UUID、dual pairing evidence 和发布输入，离线验证通过；manifest 的 `0xED OPEN` 为转换前 capture，当前 target 为 `0x72 CLOSED` | PASS |
| 1.0.15 基线 DA 售后调试 | DA OBK 权限为 `0x4040`；discovery 为 `ST_LIFECYCLE_CLOSED`、integrity VALID；permission `c` 认证后 Secure primary 196608 B 和 NonSecure primary 327680 B 分段回读均与 CLOSED 事务一致，证据为 `artifacts/hardware-regression/20260830T064437Z-closed-da-service/` | PASS |
| 1.0.15 基线 ST-Link 防未授权导出 | 认证前 `0x0C030400`/256 B 普通读取被拒绝；`close-debug` 成功后再次读取仍被拒绝 | PASS |
| CLOSED 转换基线 | ReleaseClosed + confirmed 1.0.15；`PRODUCT_STATE=0x72`；Full Regression 权限可发现但本轮未再次执行 | PASS |

### 11.3 1.0.16 CLOSED Ethernet OTA、DA 与冷启动

| 项目 | 2026-08-30 实测结果 | 结论 |
|---|---|---|
| 唯一发布 | version 1.0.16/counter16/update-sequence16，package SHA-256=`3e5ab07c7b6127dcedb46a1b4b1a695740904dd940d7128631f714d959a0b623` | PASS；身份已消耗 |
| CLOSED Ethernet OTA | 传输、reset、成对 TEST swap 和确认完成；`state=IDLE/result=0/ota_result=0/accepted_sequence=16`，全部 session 字段为 0 | PASS |
| post-OTA runtime | MCU/ATECC/pairing 验证通过，无 quarantine，relay/PWM 零输出，调参关闭 | PASS |
| V2 无负载回归 | OTA 前 29/29、OTA 后 29/29；两路阀线圈未接 | PASS（真实电流跟踪 SKIP） |
| PI telemetry gating | inactive=0，active 增长到 681、dropped=0，close 后保持 681 | PASS |
| PI 调参网络 | active 时 100 包 0% 丢包，RTT min/avg/max=`0.064/0.138/0.340 ms`；idle 后=`0.055/0.104/0.148 ms` | PASS |
| 升级后仅 ECU 冷启动 | 移除 ST-Link，ECU 断电至少 10 s 后仅 ECU 上电；runtime 安全检查 PASS；100 包 0% 丢包，RTT min/avg/max=`0.067/0.116/0.328 ms` | PASS |
| 1.0.16 DA 默认拒绝与认证 | 证据目录=`artifacts/hardware-regression/20260830T073110Z-closed-ota-1.0.16-da-service/`，`evidence.json` SHA-256=`1478a4ac2c8748e585a86756f16a7fe6384a80f3b633196b023e23667347ca6e`；认证前普通读取 rc=1/拒绝；严格 discovery 为 target `0x484`、SDA `2.4.0`、`ST_LIFECYCLE_CLOSED`、integrity VALID；permission `c` 认证 PASS | PASS |
| 1.0.16 primary 精确回读 | Secure `0x0C030000/0x30000`、NonSecure `0x08100000/0x50000`（分段）完成；`tools/verify_closed_ota_readback.py` 验证 `1.0.16+0`/counter16、`image_ok=0x01/0x01`；canonical swap size：S=`0x2DDE8`，NS=`max(1.0.15 0x8D39, 1.0.16 0x8D38)=0x8D39`；`primary-readback-audit.json` SHA-256=`034c7d99996eed055346e315c3109ba355044051f53a679771b15db79ffbc4b8` | PASS |
| 1.0.16 close-debug | `close-debug` PASS；严格 CLOSED/VALID 复核 PASS；关闭后普通未认证读取再次 rc=1/拒绝；本轮未执行 Full Regression | PASS |
| DA 后最终无探针冷启动 | 完整移除 ST-Link，ECU 断电至少 10 s 后仅 ECU 上电；MCU/ATECC/pairing、no-quarantine、relay/PWM 全零、`tuning_active=false`、telemetry=0，OTA `state=IDLE/result=0/ota_result=0/accepted_sequence=16`；100 包 0% 丢包，RTT min/avg/max=`0.060/0.116/0.331 ms` | PASS |

### 11.4 1.0.17 CLOSED Ethernet OTA、DA、冷启动与转向失联安全状态

| 项目 | 2026-08-30 实测结果 | 结论 |
|---|---|---|
| 唯一发布 | version 1.0.17/counter17/update-sequence17；package SHA-256=`75948795f39d898795b85841e4ad2e06c47738240184ff9ffbdc729fc11ab599`；双 initial 与 transport 签名离线验证通过 | PASS；身份已消耗 |
| CLOSED Ethernet OTA | 未接 ST-Link 完成传输、FINISH、reset、成对 TEST swap 和确认；最终 `state=IDLE/result=0/ota_result=0/accepted_sequence=17`，全部 session 字段为 0 | PASS |
| post-OTA runtime | MCU/ATECC/pairing/no-quarantine 通过；relay mask、两路阀目标/PWM、转向请求/应用速度及 motor-enable 均为 0；调参和高速 telemetry 关闭 | PASS |
| CAN2 电机失联 | 当前 `rx_frames=0`、protocol fault、bus passive、`SAFE_DISABLE_PENDING`，控制器持续请求安全禁用且所有转向控制量为零 | PASS（fail-closed）；主动电机控制 PENDING |
| Ethernet 性能 | OTA 前 100 包 0% 丢包，RTT min/avg/max=`0.068/0.099/0.157 ms`；OTA 后=`0.065/0.104/0.144 ms` | PASS |
| 非侵入证据 | `artifacts/hardware-regression/20260830T150744Z-closed-ota-1.0.17-runtime/` 含摘要及 SHA-256 manifest | PASS |
| 1.0.17 DA 默认拒绝与认证 | 证据目录=`artifacts/hardware-regression/20260830T154340Z-closed-da-readback-1.0.17/`；认证前普通读取 rc=1/无文件；严格 discovery 为 target `0x484`、SDA `2.4.0`、CLOSED、integrity VALID；仅 permission `c` 认证 PASS，本轮未执行 Full Regression | PASS |
| 1.0.17 primary 精确回读 | Secure `0x0C030000/0x30000`、NonSecure `0x08100000/0x50000` 六段回读完成；verifier 证明 `1.0.17+0`/counter17、`image_ok=copy_done=0x01/0x01`、S swap=`0x2DDE8`、NS swap=`0x8D38`；审计 JSON SHA-256=`8edbfecbccfbce61d724299d6dd23845eb576f457555a65cd7dc6a1b4cfb8401` | PASS |
| 1.0.17 close-debug | `Locking Debug` 和严格 CLOSED/VALID 复核 PASS；关闭后同一普通读取再次 rc=1/无文件 | PASS |
| DA 后最终仅 ECU 冷启动 | 完整移除 ST-Link、保持 JP1 断开并断电至少 10 s；MCU/ATECC/pairing/no-quarantine、relay/阀/PWM/转向零输出、调参关闭、telemetry=0；OTA IDLE/result=0/accepted17；100 包 0% 丢包，RTT min/avg/max=`0.066/0.103/0.146 ms` | PASS |
| DA 证据外部备份 | 已复制到 `/home/plac/Documents/ECU_PKI/artifacts/hardware-regression/20260830T154340Z-closed-da-readback-1.0.17/`；0700/0600、逐字节 diff 和 manifest 均通过 | PASS |

### 11.5 1.0.18 控制端白名单、优先级仲裁与撤销记录

| 项目 | 2026-08-31 结果 | 结论 |
|---|---|---|
| 网络身份 | 产品序列号 `SN-EJAHGJI`；ECU `.11`、域控 `.12`；固定遥控器 `.9`、调试/售后机 `.10` | PASS（源码与静态审计） |
| 控制边界 | 普通控制只接受 `.9/.10/.12`；调参、遥测、工厂服务和 OTA 仍只接受 `.10`；活动 sender 绑定源 IP | PASS（自动化测试） |
| 多源仲裁 | 显式 priority `1..254` 数值越大越优先；同优先级较小 sender ID 胜出；0 仅兼容旧客户端，255 保留网络紧急 | PASS（自动化测试） |
| UI | sender ID 与 priority 独立配置；活动控制期间修改任一项均要求先 RELEASE | PASS（自动化测试） |
| 主机回归 | `tools/test.sh` 的 Python/静态 199 项通过；本机无 `cc`，C 主机行为断言降级为 ARM `-Werror` 交叉编译，签名 Release 同源构建/链接通过；`tools/audit_config.sh` 与 `git diff --check` 通过；NonSecure Flash=`30752 B/311 KiB`、RAM=`91960 B/320 KiB` | C 主机运行时断言 SKIP；目标 ARM 构建 PASS |
| 唯一发布 | version 1.0.18/counter18/update-sequence18；package SHA-256=`4586f106b91fe91f293643a356105c26bf3af74161ac28034fc3494f999a517a` | **REVOKED / 禁止刷写**；身份已消耗 |
| 离线密码学/格式 | transport ECDSA、双 initial/加密 update OEMiROT 签名、镜像 identity/counter/dependency、1.0.17 previous-swap reference 与双 key-area hash 均固定并验证 | PASS |
| CLOSED Ethernet OTA | 包在安装前撤销并改名为 `.recu.REVOKED_DO_NOT_FLASH`；当前板仍为 accepted sequence 17 | **NOT RUN / REVOKED** |
| post-OTA runtime/冷启动 | 从未安装，不得用离线结果替代实机验收 | **NOT RUN** |

### 11.6 1.0.20 K12/锁存急停安全发布准备

| 项目 | 2026-09-01 结果 | 结论 |
|---|---|---|
| K12 启动策略 | ATECC/MCU 认证、成对镜像确认、PB2 连续健康 20 ms 后只闭合 K12；无需 Ethernet lease；普通控制断开及隔离的阀/CAN 故障保留 K12，自动输出归零 | PASS（主机真值表、源码审计与目标编译） |
| 锁存急停 | `.9/.10/.12` 任一来源可断开 K12并置 RAM latch；断线不清除；仅显式 V2 reset、认证/确认/非关键故障且 PB2 释放后重新连续健康 20 ms 才恢复 K12；V1 只能置位 | PASS（自动化测试） |
| OTA 实体急停门禁 | 主机在 BEGIN、每个 CHUNK、FINISH 及 reset/确认前后监视新鲜 PB2；新 Secure 镜像在服务入口和确认点再次强制 PB2；K12/自动输出在 OTA 期间硬断 | PASS（主机/源码/构建）；实物连续保持 PENDING |
| 1.0.18 撤销 | 从未安装；包改名 `.REVOKED_DO_NOT_FLASH` 并保留 metadata、固定哈希和 revocation marker 作取证 | PASS；身份 18 永久保留 |
| 1.0.19 撤销 | 签名后严格审计发现 NonSecure initial payload=31096 B、encrypted update payload=31104 B；未外发、未安装，包已隔离 | PASS（fail-closed）；身份 19 永久保留 |
| 打包器修复 | raw Secure/NonSecure 在任何签名之前统一按 16 B 以 `0xFF` 对齐；空 payload 拒绝；行为测试和静态顺序门禁通过 | PASS |
| 最终主机/构建回归 | `tools/test.sh` 227 项、`audit_config.sh`、`git diff --check`、签名应用与 ReleaseOpen/ReleaseClosed 全部通过；S Flash/RAM=`57924/29764 B`，NS=`31092/91960 B`，Open/Closed loader Flash=`51742/51758 B` | PASS；本机无 native `cc`，C 行为断言仅 ARM `-Werror` compile-only，运行时断言 SKIP |
| 唯一发布 | version 1.0.20/counter20/update-sequence20；package SHA-256=`9c370f279fde039cadb329390e9dd857a9235fdea81eda247ec92e7ee8263ace` | PASS；身份已消耗 |
| 四文件哈希 | metadata=`f8509da9a6f1b635ad3e53abd0df2a23e106429ab8b13fdcf5f4f040900f40bd`；S initial=`e15ad3c57afe9f3b105e41e433cf7307d8611dbe3b23c57800cbe7f0fa279e5f`；NS initial=`3729dddf4bdceb9f271dbccb7228a0de5f82b03d766196f5a5fcb0376c36e837` | PASS（精确固定） |
| 离线密码学/几何 | transport ECDSA、双 OEMiROT 签名、dependency/counter、direct 1.0.17 previous-swap 和双 key-area hash 验证；S payload=`186592/186592 B`、NS=`31104/31104 B`；swap S=`0x2DE08`、NS=`0x7EA8` | PASS |
| CLOSED Ethernet OTA | 只能从更新后的 macOS 工具、固定服务地址 `172.16.0.10` 向 ECU `172.16.0.11` 执行；当前板仍为 accepted sequence 17 | **PENDING** |
| post-OTA runtime/冷启动 | 必须验证 accepted sequence 20、ATECC/MCU pairing、双确认、无 quarantine、K12/急停真值表、自动输出归零、PI telemetry 关闭、网络延迟和仅 ECU 冷启动 | **PENDING** |

2026-09-05 实板更新：上表保留 2026-09-01 发布准备时的状态。本机 Linux 已通过
Ethernet 将 SN-EJAHGJI 从 1.0.17 更新到 1.0.20（accepted_sequence=20）；
双镜像运行确认、同一配对身份、原 PI 参数保留、实体急停保持时零输出、遥测订阅/
取消订阅和升级后仅 ECU 冷启动通过。继电器命令/控制安全 30 项及真实来源 IP
仲裁/并行急停/服务限制 22 项通过，临时 `.9/.12/.13` 已删除；这不是触点测量。
接阀 100/200 mA 验收和 100/200/500 mA PI 候选实测完成，两路 Kp=400 不变、
Ki=8000 已写入 Flash 并 RELOAD 读回（generation=3、CRC32C=951452805）。
随后操作者再次断电上电，generation=3 新参数掉电保持 PASS（独立记录
`pi-cold-start.json`）：配置/CRC 不变、启动后无控制帧、IDLE/仅 K12、阀目标/
PWM/反馈为零、高速遥测未启动；100 包无丢包，RTT 平均/最大 0.121/0.241 ms。
新参数下中性/前进 200 mA/后退 200 mA 波形回传期间各 100 包无丢包，平均
RTT 为 0.118/0.110/0.111 ms，最大 0.373 ms；关闭波形后停止高速发送。
ECU 仍为原签名 1.0.20，未因临时线束问题更改固件保护。完整记录和日志链接见
该版本的台架记录。

以下项目仍为 PENDING，不得继承历史记录或把软件 mask 当作硬件 PASS：

- 阀的 0–2 A 全范围、实际液压负载/热态、外部电流标定、开路/短路/过流和换向故障注入；100–500 mA 台架结果不能替代这些项目；
- K1..K27 实际触点、车辆负载、急停/驻车/启动/高低转速/龟兔档失电恢复；
- CAN1/J1939 车辆报文、速度输入和油温/油压/水位等传感器实信号；
- 接入真实转向电机后的 CAN2 enable/速度/停止/超时/DTC/bus-off/急停测试；
- 电源瞬态、IWDG/CSS、PHY 故障、EMC、环境、热和耐久型式试验；
- 第 8.2 节 OTA-P02..P17 专用可恢复样件发布/型式鉴定。

## 12. SN-EJAHGJQ 正式台架结果（2026-09-06）

本节只适用于 SN-EJAHGJQ（ECU `.21`、域控 `.22`、firmware 1.0.22、accepted
sequence 22），不能用来覆盖上一节 SN-EJAHGJI 的 generation/CRC 或历史结论。

| 项目 | 实测结果 | 结论 |
|---|---|---|
| 身份与安全前置 | UID `003900443434511232383537`、ATECC `01236acf4e275ef9ee`、auth result 0、CLOSED、普通读出拒绝，DA/Full Regression 已单独通过 | PASS |
| 功能控制 | 30/30；继电器命令、发动机高低速脉冲、启动限时、龟兔档、阀互锁/安全换向、超时归零、急停锁存/复位 | PASS（软件状态/mask；非全部触点电测） |
| 多来源网络 | 22/22；`.22/.10/.9` 仲裁和并行急停正确，`.13` 普通控制拒绝，OTA 仅 `.10` | PASS |
| PI 候选 | `400/4000` 平均稳定约 526.3 ms；`400/8000` 约 313 ms；`400/10000` 约 277.5 ms；`600/8000` 约 338.7 ms | 选择 `400/8000` |
| Flash 参数 | 前/后 Kp=400、Ki=8000，generation=1，CRC32C=`2378242392`，valid=1、dirty=0、defaults=0 | PASS |
| 真实掉电保持 | 断电至少 10 s 后上述 generation/CRC/参数不变，冷启动为 IDLE/仅 K12/双阀零输出 | PASS |
| 冷启动后接阀 | 前/后 100 mA 均值 99.28/99.53 mA；200 mA 均值 199.13/198.71 mA；结束零输出、无 fault | PASS |
| 波形网络性能 | 1 kHz 会话内三工况 RTT 平均约 0.107–0.117 ms、最大 0.403 ms、零丢包；会话外停止高速回传 | PASS |
| 最终空闲网络 | 100/100、0% 丢包，RTT min/avg/max=`0.068/0.110/0.148 ms` | PASS |

原始 JSON/CSV 位于
`artifacts/hardware-regression/20260906T133532Z-sn-ejahgjq-valve-pi/`。此结果只覆盖
未接车辆的 100/200 mA 小电流台架范围；0–2 A、热态液压负载、外部电流标定、
阀故障注入、真实 CAN2 转向电机、CAN1/传感器/速度、继电器触点和整车型式项目
仍按第 11 节末尾清单处理。

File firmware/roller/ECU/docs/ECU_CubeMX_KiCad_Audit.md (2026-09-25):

# ECU KiCad / STM32CubeMX 配置审查

审查日期：2026-08-30；安全状态更新：2026-09-01

MCU：STM32H563ZIT6，LQFP144

工具：STM32CubeMX 6.18.0、STM32CubeH5 1.7.0

硬件依据：`pcb/roller/ecu` KiCad 工程

兼容层实现参考：[ecu_protocol.c](../NonSecure/App/Src/ecu_protocol.c)；
当前硬件连接以 KiCad 工程为准。CAN2 电机协议依据为厂商
[方向盘舵机使用手册](https://ae-pic-a1.aliexpress-media.com/kf/Sf252692b27884931b38077b0e5716cf1s.pdf)

## 1. 审查结论

`ECU.ioc` 已从新建工程补齐为可开发基线。引脚、外设归属、关键初始电平、
CAN 位时序、ETH MAC、DMA、定时器和 TrustZone 属性均已写回 `.ioc`，并非只
修改生成 C 文件。应用逻辑放在 `Secure/App`、`NonSecure/App`、
`Secure_nsclib` 和用户维护的 CMake 文件内；CubeMX 再生成不会删除这些文件。

当前 PCB 的 PB8/PB9 物理网络接反，已按用户决定改为 Secure GPIO 开漏模拟
I²C：`PB8=SW_I2C_SDA`、`PB9=SW_I2C_SCL`，无需飞线。软件总线包含释放、
时钟拉伸超时和 stuck-low 恢复；ATECC 启动另行无条件执行
`START + 9 clocks + START + STOP`、reset/sleep 归一化，并在最长 725 ms 的有界
恢复期间服务 IWDG。ATECC608C 已在 Secure 域完成探测、锁区、
P-256 随机挑战和 MCU/安全芯片配对。总线、芯片、锁状态、配置 CRC、序列号、
MCU UID 或签名任一不匹配都会禁止执行器 ARM 和 OTA 试运行确认。

LwIP 在 STM32H5 当前 CubeMX 工程中作为项目自有中间件集成。CubeMX 继续生成
ETH HAL、描述符和引脚初始化；LwIP、LAN8742 接口和 ECU UDP 应用放在生成目录
之外。这样既保留 `.ioc` 的硬件配置，又避免 UI 再生成覆盖协议代码。

## 2. 已持久化的 CubeMX 配置

| 子系统 | 当前设置 | 设计约束 |
|---|---|---|
| 时钟 | HSE 25 MHz，SYSCLK/HCLK 250 MHz，CSS 开启 | HSE 故障进入 NMI 并关断输出 |
| TrustZone | ADC12、SPI4、FDCAN1、FDCAN2、TIM4、TIM6、TIM7、IWDG 为 Secure；两个 FDCAN 均为 `SEC|NPRIV`，对应 GPIO、IRQ、DMA 受保护 | NonSecure 不能直接访问继电器、阀 PWM、车辆 CAN1、CAN2 转向或安全采样 |
| 急停 | PB2，Secure 双边沿 EXTI，标签 `ESTOP_DETECT` | 高电平立即硬关 K12/TPIC/PWM 并锁存故障；低电平连续健康 20 ms 后只恢复 K12，自动输出仍须清故障和中性 rearm |
| 软件 I²C | PB8=软件 SDA、PB9=软件 SCL，GPIO Output、Open Drain、上电 High | 仅适用于当前接反的 PCB；无条件 9-clock host-reset 同步与 725 ms 上限属于 Secure 自维护代码，内部不上拉 |
| TPIC6A595 | SPI4 Secure；PE2 SCK、PE6 MOSI；8 bit、TX only、3.90625 Mbit/s | PE3 OE_N 上电 High；PE5 CLR_N、PE7 BUF_EN、PE4 RCK 上电 Low |
| 阀 PWM | TIM4 CH1=PB6、CH2=PB7；中心对齐 20 kHz；初值 0 | 正反向互锁；CH4=1 在中心对齐计数谷底、即 PWM 导通脉冲中心触发 ADC2 |
| 慢速 ADC | ADC1 九路，TIM6 TRGO 1 kHz，GPDMA1 CH0 circular | 外部量、VREFINT、MCU 温度；采样顺序见下表 |
| 电流 ADC | ADC2 两路，12.5 cycles，TIM4 TRGO，GPDMA1 CH1 circular；ADC2/GPDMA IRQ priority 1 | 前进 PA4、后退 PA6；20 kHz 电流 PI、上电零点校准、VREFINT 补偿和硬故障阈值 |
| FDCAN1 | Secure Classic CAN 250 kbit/s，80% 采样点，自动重发；0 standard/6 extended filters | 只读车辆 J1939 接口；只接受六个 PGN，经版本化 NSC 快照提供工程量，不开放 raw CAN/TX |
| FDCAN2 | Classic CAN 250 kbit/s，2 extended filters，禁止自动重发 | Secure 独占的转向电机节点 1 速率控制；错误时不重放过时命令 |
| 速度输入 | TIM2 CH1=PA0；1 MHz、32 bit、输入滤波 8、IRQ | 20000 pulse/km，1500 ms 丢信号，IIR α=0.2 |
| Ethernet | RMII、MAC `8A:EA:B5:00:00:02`；PB14 PHY reset 上电 Low | ETH 初始化前保持复位 30 ms，再释放 LAN8742 |
| IWDG | Secure，LSI、Prescaler 32、Reload 1999，约 2 s | NonSecure 只能通过带递增 heartbeat 的 NSC 服务刷新 |

ADC1 DMA 固定顺序：

| 索引 | 信号 | MCU 通道 |
|---:|---|---|
| 0 | OIL_LEVEL_ADC | PC0 / ADC1_IN10 |
| 1 | OIL_TEMP_ADC | PC2 / ADC1_IN12 |
| 2 | WATER_LEVEL_ADC | PC3 / ADC1_IN13 |
| 3 | TEMP_SENSOR_1_ADC | PA3 / ADC1_IN15 |
| 4 | TEMP_SENSOR_2_ADC | PA5 / ADC1_IN19 |
| 5 | ENGINE_SENSOR_ADC | PB0 / ADC1_IN9 |
| 6 | VBAT_12V_ADC | PB1 / ADC1_IN5 |
| 7 | VREFINT | internal |
| 8 | MCU temperature | internal |

ADC2 索引 0 为前进阀电流 PA4，索引 1 为后退阀电流 PA6。车辆状态沿用
`mV = raw × 3360 / 4096`，发动机信号达到 3200 mV 判定运行。尚未取得传感器
标定曲线的通道只上报原始值/毫伏值，不编造工程量或报警阈值。

## 3. 必须在 CubeMX UI 中这样核对

正常情况下不需要再手工修改。使用 CubeMX 6.18 打开项目根目录 `ECU.ioc`；
不要从 NUCLEO 模板重建工程。若 UI 显示黄色冲突或要求迁移固件包，先取消生成
并确认仍使用 STM32CubeH5 1.7.0。

### 3.1 Secure context 和 PB8/PB9

1. 在 Pinout 页面切换到 **Cortex-M33 Secure** context。
2. PB8 选择 `GPIO_Output`，User Label 为 `SW_I2C_SDA`；PB9 选择
   `GPIO_Output`，User Label 为 `SW_I2C_SCL`。
3. 在两脚 GPIO 参数中确认 Output Level=`High`、Mode=`Output Open Drain`、
   Pull=`No pull-up and no pull-down`、Speed=`Low`、Pin Attribute=`Secure`。
4. **不要启用 I2C1，也不要把 PB8/PB9 改为硬件 AF。** 当前 PCB 只有上述
   反常映射才能不飞线工作。
5. `System Core > GTZC_S` 中不需要配置 I2C1；应确认 SPI4、ADC12、**FDCAN1、
   FDCAN2**、TIM4、TIM6、IWDG 为 Secure，并启用相应 Illegal Access interrupt。
   两个 FDCAN 必须在 `.ioc` 和生成的 `gtzc_s.c` 中都精确为
   `GTZC_TZSC_PERIPH_SEC|GTZC_TZSC_PERIPH_NPRIV`，不能只依赖 Pinout context。
6. CubeMX 6.18 当前会把 SRAM3 的 privilege vectors 全部生成为 privileged-only，
   且 `.ioc` 不保存手工加入的 MPCBB3 privilege 数组。ETH DMA 以非特权总线主设备
   访问 NonSecure 描述符，因此 `Secure/Core/Src/gtzc_s.c` 的
   `GTZC_S_Init 2` USER CODE 会在生成配置之后，仅将 SRAM3 前 64 KiB
   (`0x20050000..0x2005FFFF`) 改为允许非特权访问。该段由
   `ProjectManager.KeepUserCode=true` 保留；不要删除或移出 USER CODE 标记。
   其余 SRAM3 继续保持 privileged-only。

### 3.2 TPIC 和安全初始电平

1. `Connectivity > SPI4`：Master、Simplex Transmit Only、8 Bits、Prescaler
   32，计算速率应为 3.90625 Mbit/s。
2. PE2=`SPI4_SCK/TPIC_SRCK`，PE6=`SPI4_MOSI/TPIC_SER`，两脚均为 Secure。
3. PE3 `TPIC_OE_N` 初值 High；PE5 `TPIC_CLR_N`、PE7
   `TPIC_CTRL_BUF_EN`、PE4 `TPIC_RCK` 初值 Low。任何一个初值变化都可能造成
   上电瞬态吸合，不能接受。

### 3.3 ADC、DMA 和 TIM4/TIM6

1. ADC1 regular group 为 9 ranks，触发源 `TIM6 TRGO / Rising edge`，DMA
   circular；ADC2 为 2 ranks，触发源 `TIM4 TRGO / Rising edge`。
2. GPDMA1 CH0/CH1 分别为 ADC1/ADC2，source fixed、destination increment、
   half-word、circular，并标记 Secure channel/source/destination；Security 页的
   Channel Privilege 必须为 **Privileged**。ADC DMA 的 linked-list node 与目标缓冲区
   位于 privileged-only Secure SRAM，设成 Non-Privileged 会触发 GPDMA `USE` 错误并
   使 ADC 快照保持为零。
3. TIM4 Counter Mode=`Center Aligned mode 1`，Prescaler=0，Period=6249；
   CH1/CH2 PWM Pulse=0。ADC2 两个 regular rank 均为 12.5 cycles；ADC2 和
   GPDMA1 Channel1 IRQ 抢占优先级均为 1。
4. 保留虚拟 `PWM Generation4 No Output`，Pulse=1，Master TRGO=`OC4REF`。
   中心对齐 PWM1 在计数谷底跨越导通区，该触发点位于导通脉冲中心附近；
   删除 CH4 或恢复 3125 都会破坏 20 kHz 电流采样相位。
5. TIM6 Update Event 频率为 1 kHz，并启用 Secure global interrupt。

### 3.4 Ethernet 与 FDCAN

1. 切换到 **Cortex-M33 NonSecure** context。ETH Mode=`RMII`，
   MAC=`8A:EA:B5:00:00:02`；核对 RMII 引脚与 KiCad
   网络一致，PB14 `RMII_NRST` 初值 Low。
   PB14 必须保持初值 Low：`eth.c` 的 CubeMX `USER CODE BEGIN ETH_Init 0` 会继续保持
   nRST 30 ms，然后释放并等待 50 MHz REFCLKO 稳定，随后同一函数才进入
   `HAL_ETH_Init()`。不得把复位释放移回 `ECU_AppInit()`；LAN8742A 在本板上是
   MCU RMII 时钟源，先初始化 ETH、后释放 PHY 会形成冷启动竞态。
2. **不要在 NonSecure context 启用 FDCAN。** 切换到 **Cortex-M33 Secure**，
   确认 PD0=`FDCAN1_RX`、PD1=`FDCAN1_TX`，两引脚均为 Secure。FDCAN1 保持
   Classic CAN 250000 bit/s：kernel 25 MHz、Prescaler=4、Seg1=19、Seg2=5、
   SJW=4，Auto Retransmission/Transmit Pause enabled；Standard Filters=0、
   Extended Filters=6，IT0 优先级 5。六个 J1939 PGN/Mask 由 Secure 应用配置。
3. 同一 Secure context 中，PB12=`FDCAN2_RX`、PB13=`FDCAN2_TX`，两引脚和
   FDCAN2 peripheral attribute 均为 Secure。位时序与 FDCAN1 相同，
   Transmit Pause enabled；**Auto Retransmission 必须 disabled**，避免总线恢复后
   硬件重放已超时的非零转向命令。
4. FDCAN2 Standard Filters=0、Extended Filters=2。Secure 应用只配置
   `0x05800001` SDO response 和 `0x07000001` heartbeat 两个精确扩展过滤器，
   global filter 拒绝所有其他标准/扩展/远程帧。FDCAN2 IT0 与 1 ms TIM6
   状态机使用相同抢占优先级 2，使两条会访问同一 FDCAN HAL handle 的路径串行化；
   通知和回调只在 Secure 域存在。高优先级 ADC/EXTI 故障路径只能提交原子
   safe request，由 TIM6 消费，不得直接调用 FDCAN HAL。
5. STM32H563 的 [ES0565 Rev.8 §2.2.34](https://www.st.com/resource/en/errata_sheet/es0565-stm32h562xx563xx573xx-device-errata-stmicroelectronics.pdf)
   要求 FDCAN1/FDCAN2 使用相同 security/privilege 属性。本工程统一为
   `SEC|NPRIV`，Secure 初始化必须保持 FDCAN1 在 FDCAN2 之前，共用 HSE/DIV1
   kernel clock 和引用计数；生成的 `NVIC_INIT_ITNS1_VAL` 必须为 `0x00002000`。
   这是强制勘误 workaround，不得把 CAN1 单独移回 NonSecure。
6. TIM2 捕获优先级 6。生成后用 `audit_config.sh` 同时核对 `.ioc`、Secure
   `fdcan.c`、`gtzc_s.c`、ITNS/IRQ、单一 callback dispatcher，以及 NonSecure
   不存在 FDCAN 生成文件、HAL handle 或应用调用；任一层不一致都不得发布。

### 3.5 LwIP 的特殊说明

不要在 CubeMX 中另加一份 LwIP，也不要复制 `MX_LWIP_Init()` 代码。本工程使用：

- `ThirdParty/LwIP`：固定版本的协议栈源码（避免 CubeMX 清理保留名 `Middlewares`）；
- `Drivers/BSP/Components/lan8742`：PHY 驱动；
- `NonSecure/App/Network`：本板 `ethernetif` 与 `lwipopts.h`；
- `NonSecure/App/Src/ecu_network.c`：静态 IP 和 UDP 协议。

`NonSecure/CMakeLists.txt` 顶部明确标注“generated only once”，CubeMX 后续不会
重写现有文件。生成的 `NonSecure/Core/Src/eth.c` 仍是 ETH HAL 唯一硬件实例，
应用层不会重复定义 `heth`、描述符或 MSP。

本版硬件的 R70=10 kOhm、C65=100 nF 只能提供约 1 ms 的 nRST 延迟，不能满足
LAN8742A 规定的“外部电源稳定后至少 25 ms 再释放 nRST”。固件因此在 CubeMX
保留区内强制执行 30 ms 复位。R41 把 PHYAD0 固定为地址 0；驱动在地址 0 读取
PHYID1/PHYID2 并校验 `0x0007/0xC13x`，明确拒绝断开的 MDIO 总线返回的
`0xFFFF/0xFFFF`。PHY 暂时不可用时 LwIP 与安全主循环继续运行，250 ms 轮询会
自动重试，连续管理接口读错误也会退回重新探测，而不会进入 `Error_Handler()`。
HAL MDIO 在总线断开时可能返回 `HAL_OK + 0xFFFF`，底层读函数同样把该组合视为
读错误，避免运行期被误判成某个合法速率。HAL 单次 MDIO 等待上限为 5 ms；
对 LAN8742 组件默认的 0..31 地址扫描，I/O 包装层在调用 HAL 前拒绝地址 1..31，
所以断线或总线卡死时整轮探测最多消耗一次 HAL 超时，而不是累计 32 次。

### 3.6 Project Manager

保持 Toolchain=`CMake`、Keep User Code=`enabled`、删除旧生成文件=`enabled`。
每次 UI 生成后必须执行：

```sh
./tools/audit_config.sh
./tools/test.sh
./tools/build.sh Debug
./tools/build.sh Release
```

`tools/build.sh` 对 Secure/NonSecure 和 Debug/Release 使用独立构建目录，避免
CubeMX 顶层 ExternalProject 在切换配置时复用错误对象。

### 3.7 OEMiROT 应用 SAU 边界

保持 `partition_stm32h563xx.h` 中 SAU 为 disabled、`ALLNS=1`，region 0..7
全部 disabled。这与 ST 的 STM32H563 OEMiROT TrustZone 应用模板一致：Cortex-M33
地址别名的初始属性由 IDAU 决定，Flash 安全水印与 GTZC/MPCBB 再约束 Flash、
外设和 DMA 主设备。Secure `main.c` 只清理由 OEMiROT 继承的 MPU region，不再
部分重写并启用 SAU；否则 RSS/DA 遗留且未清除的 comparator 会重新生效。

Debug Authentication 或 Hotplug 会进入 RSS，属于侵入式现场。认证成功后必须
执行受控复位，再判断应用状态；不得把 resetless Hotplug 后读取到的 SAU 或故障
寄存器当成无探针冷启动现场。

## 4. 再生成安全边界

| 所有者 | 目录/文件 | CubeMX 行为 |
|---|---|---|
| CubeMX | `*/Core`、`*/mx-generated.cmake` | 可再生成；自定义入口只放 USER CODE 区 |
| 项目 | `Secure/App`、`NonSecure/App` | CubeMX 不管理 |
| 项目 | `Secure_nsclib/safety_api.h` | 共用 ABI，版本化维护 |
| 项目 | Secure/NonSecure `CMakeLists.txt` | CubeMX 只首次创建，不覆盖现有文件 |
| 项目 | `ThirdParty/LwIP`、`Drivers/BSP` | 固定依赖，CubeMX 不管理 |
| 项目 | `tools`、`tests`、`docs` | CubeMX 不管理 |

Secure NSC veneer 位于 `Secure/Core/Src/secure_nsc.c` 的 USER CODE 区，所有
NonSecure 指针先做 CMSE 地址范围和访问属性检查，再复制到 Secure 栈上验证。
NonSecure 不能传入裸 TPIC 位图，只能提交有范围约束的高层执行器结构。
启动、急停解除或普通控制退出时始终保持 TPIC `OE_N=High`，先连通 AHCT541、
清空寄存器，再经 SPI 移入并锁存**仅 K12(bit22)** 的人工驾驶许可基线，最后才
打开 `OE_N`。普通 ARM 在该基线上追加受控输出，不允许产生 32 位全零脉冲；
关键故障、实体/网络急停和 OTA 则保持 `OE_N=High` 并把全部位硬清零。禁止在
缓冲器断开时用无效 RCK 脉冲代替该流程。

## 5. 下一版 PCB 强制 ECO：恢复硬件 I²C

ECO 编号建议：`ECU-R2-I2C-001`。

1. 原理图将 MCU PB8 接物理 SCL、PB9 接物理 SDA，禁止继续沿用当前交换网络。
2. 核对两线各有适合总线电容和目标速率的外部上拉，电压域与 ATECC608C I/O
   一致；保留 SCL/SDA/GND 测试点。
3. 新板固件在 CubeMX Secure context 中移除 PB8/PB9 GPIO Output，启用 I2C1：
   PB8=`I2C1_SCL`、PB9=`I2C1_SDA`、100 kHz、Analog Filter enabled，并把
   I2C1 设为 Secure。
4. 删除 `software_i2c.c` 的构建引用，ATECC608C 驱动只通过受限 Secure 服务
   暴露签名/验证等高层操作，不向 NonSecure 开放任意寄存器访问。
5. 投板评审必须把 PCB 网络表与 `.ioc` 引脚表交叉检查，并做 idle、ACK、
   stuck-low recovery、时钟拉伸和掉电回灌测试。

当前板代码和 UI 中均以 `SW_I2C_PCB_R1` capability 标识此临时方案，避免它
被误认为下一版的长期设计。

## 6. OEMiROT 与 Option Bytes：CubeMX 外的受控步骤

Option Bytes、OBKeys 和产品生命周期不属于 `.ioc`。当前 OEMiROT 样件状态为：

- STM32H563 Device ID `0x484`，`TZEN=0xB4`，当前产品状态为 CLOSED
  (`0x72`)；
- `BOOT_UBE=0xB4`，`SECBOOTADD=0x0C000000` 且 `SECBOOT_LOCK=0xB4`；
- Bank1 全部 Secure、Bank2 NonSecure，禁止 Bank Swap；
- WRP group 0..3 保护 OEMiROT，HDP Bank1 `0x00..0x17` 隐藏 boot+scratch；
- DA OBK 权限为 `0x4040`：仅允许证书认证的 HDPL3 S/NS 临时调试和破坏性
  Full Regression；不开放 HDPL1/2，也不允许 Partial Regression；
- Secure SRAM2 在 reset 清除并启用 ECC。

`tools/provision_oemirot_open.sh` 在 OPEN 制造或 Full Regression 恢复的破坏性迁移前
核对芯片、探针和产品状态，备份完整 2 MiB Flash、Option Bytes、持久区及
SHA-256，并按阶段写日志。本样件曾完成 CLOSED/DA 验证，随后实际执行
Full Regression 并重建为 OPEN/ReleaseOpen；该过程保留为历史恢复证据。之后
Secure/NonSecure primary 完成 `1.0.15+0`、security counter=15、
`image_ok=0x01/0x01`、OTA `accepted_sequence=15` 的密码学审计，并通过不可变
CLOSED 事务安装 ReleaseClosed。事务目录为
`artifacts/device-backups/stm32h563-066BFF565456857187210935-20260830T063129Z-closed-transition/`，
UUID=
`0f3537fe-c04d-4298-ba50-995773e07a6a`，最终 phase=
`product_state_closed_verified`。随后在保持 `0x72 CLOSED` 期间通过 Ethernet 安装
1.0.16/counter16/accepted-sequence16，随后又安装并完整验收
1.0.17/counter17/accepted-sequence17；JP1 保持断开。不可逆转换、Full Regression
恢复和 DA 售后边界见 `ECU_Security_and_OTA.md`。

1.0.15 CLOSED 转换/恢复基线及 1.0.16 历史运行证据如下；当前板仍运行已验收的
1.0.17。未安装的 1.0.18 已撤销；1.0.19 因签名后离线审计发现 NonSecure
initial/update 几何不一致而撤销。修正打包对齐后的 1.0.20 离线发布与实机 OTA
状态见安全/验收文档：

- ATECC 在持续上电条件下，以 option-byte reset、under-reset UID read、final reset
  的 hostile 顺序连续回归 20 次，20/20 均恢复配对认证、accepted15、零输出和
  Ethernet。实现使用 25 ms 步长、最长 725 ms 的启动预算，每次尝试服务 IWDG，
  超时保持 quarantine；
- pairing A sector=`0x080E0000`，B sector=`0x080E2000`。B 从全擦除修复后与 A
  committed record 字节一致，16 KiB dual-store SHA-256=
  `45f1f08b626f3934f2359e4d44b1993c9333c5275f62870d74a77caeb6c9f310`。CLOSED
  finalizer 已在任何目标写操作前完成独立 readback、dual verify 并持久化
  `pairing_store_dual_verified`，其后才进入 `pre_mutation_evidence_verified`；
- 当前无阀线圈功能回归 29/29，真实阀线圈为 SKIP。PI 调参高速遥测严格随 session
  门控，frames=`0 → 175 → 175`、drop=0；调参 RTT min/avg/max=
  `0.059/0.114/0.290 ms`，退出空闲为 `0.059/0.127/0.185 ms`；
- Full Regression recovery 已生成并离线验证通过，实物包为
  `artifacts/device-backups/stm32h563-066BFF565456857187210935-20260830T064244Z-final-1.0.15/`，
  schema v4 绑定上述 CLOSED UUID、精确 release/package 与 dual pairing evidence。manifest
  中 `capture.product_state="0xED OPEN"` 是 CLOSED 前不可变恢复输入，不是当前状态；
  `target.product_state="0x72 CLOSED"` 才是当前已验证生命周期；
- `artifacts/hardware-regression/20260830T064437Z-closed-da-service/` 证明认证前普通
  ST-Link 读取被拒绝，permission `c` 认证后 Secure/NonSecure primary 回读与
  CLOSED 事务一致，close-debug 后未认证读取再次被拒绝。本轮未再次执行
  破坏性 Full Regression；
- 唯一签名的 1.0.16/counter16/sequence16 包 SHA-256=
  `3e5ab07c7b6127dcedb46a1b4b1a695740904dd940d7128631f714d959a0b623`，已通过
  CLOSED Ethernet OTA 完成传输、reset/TEST swap 和确认；最终
  `state=IDLE/result=0/ota_result=0/accepted_sequence=16`，session 字段全 0；
- post-OTA MCU/ATECC/pairing、no-quarantine、零输出和调参关闭 PASS。OTA 前/
  后无阀线圈回归均为 29/29，真实电流跟踪仍 SKIP。telemetry 严格门控为
  `0 → 681 → 681`、drop=0；active/idle RTT 分别为
  `0.064/0.138/0.340 ms` 和 `0.055/0.104/0.148 ms`；
- 完整移除 ST-Link、断电至少 10 s 后仅 ECU 冷启动 PASS，100 包 0% 丢包，
  RTT min/avg/max=`0.067/0.116/0.328 ms`；
- 1.0.16 发布后 DA 终验证据为
  `artifacts/hardware-regression/20260830T073110Z-closed-ota-1.0.16-da-service/`：
  认证前普通读取 rc=1/拒绝；严格 discovery 确认 target `0x484`、SDA `2.4.0`、
  CLOSED、integrity VALID；permission `c` 认证 PASS。Secure
  `0x0C030000/0x30000` 与分段 NonSecure `0x08100000/0x50000` 回读经
  `tools/verify_closed_ota_readback.py` 验证为 `1.0.16+0`/counter16、
  `image_ok=0x01/0x01`。canonical swap size 为 Secure `0x2DDE8`、NonSecure
  `max(1.0.15 0x8D39, 1.0.16 0x8D38)=0x8D39`；审计 JSON SHA-256=
  `034c7d99996eed055346e315c3109ba355044051f53a679771b15db79ffbc4b8`，
  `evidence.json` SHA-256=
  `1478a4ac2c8748e585a86756f16a7fe6384a80f3b633196b023e23667347ca6e`；
- close-debug 后严格 CLOSED/VALID 复核 PASS，普通未认证读取再次 rc=1/拒绝；
  本轮未执行 Full Regression。完整移除 ST-Link 并断电至少 10 s 后的最终仅 ECU
  冷启动 PASS：MCU/ATECC/pairing、no-quarantine、relay/PWM 全零、调参关闭、
  telemetry=0，OTA IDLE/result0/ota_result0/accepted16；100 包 0% 丢包，
  RTT min/avg/max=`0.060/0.116/0.331 ms`。

OEMiROT 固定布局由 `Shared/ecu_flash_layout.h` 单点定义：boot 128 KiB、scratch
64 KiB、Secure primary/secondary 各 192 KiB、NonSecure secondary/primary 各
320 KiB，中间 `0x0C0E0000..0x0C0FFFFF` 的 128 KiB 专用于安全身份、OTA 日志
和阀参数。应用 vector 分别为 `0x0C030400` 和 `0x08100400`。构建期 ASSERT 阻止
镜像、trailer 或持久区互相越界；不得再用旧的直接 Secure/NonSecure linker 布局
烧录 OEMiROT 样件。

NonSecure `.bss` 中包含 ETH 描述符及全部 LwIP pool；链接片段
`NonSecure/App/Linker/eth_dma_sram3_guard.ld` 强制它不超过
`0x20060000`。这样后续静态数据增长超出 GTZC 已审查的 64 KiB DMA 窗口时会在
链接阶段失败，而不是在实机上表现为隐蔽的 Ethernet DMA 超时。
每次主循环最多处理 `ETH_RX_DESC_CNT=4` 个接收包，持续流量不能饿死 Secure
心跳、CAN 和控制超时；PHY MDIO 忙等待从 HAL 默认 1000 ms 收紧为 5 ms，并在
HAL 前拒绝地址 1..31 的无效 PHY 扫描。V1/V2 status、steering、diagnostic、
security 周期发送采用绝对截止时间和独立相位，同一 HAL 毫秒最多提交一类周期
应用帧，避免正常周期广播在同一轮耗尽 4 个 TX descriptor。三项均位于不会被
CubeMX 重新生成覆盖的
自有源文件/CMake 配置，并由 `audit_config.sh` 锁定。
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

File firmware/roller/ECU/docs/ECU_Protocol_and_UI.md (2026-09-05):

# ECU V2/A5 兼容通信协议、继电器映射与调试 UI

## 1. 网络参数

| 项目 | 配置 |
|---|---|
| 设备身份 | `SN-EJAHGJI`，旧版算法解算为 roller / device ID 1 |
| ECU/controller | `172.16.0.11/16`，MAC `8A:EA:B5:00:00:02` |
| 遥控器 | 固定 `172.16.0.9/16`，允许普通控制 |
| 调试/售后主机 | 固定 `172.16.0.10/16`，允许普通控制、调参和 OTA |
| 域控/IPC | 本设备解算地址 `172.16.0.12/16`，允许普通控制 |
| 状态 | UDP 50001，ECU 广播，50 ms |
| 控制 | UDP 50002，普通命令仅接受 `.9/.10/.12`，推荐 20 Hz |
| 诊断 | UDP 50003，ECU 广播，100 ms |
| 阀遥测 | UDP 50004，订阅后 ECU 单播，1 kHz 样本、批量发送 |
| 参数服务 | UDP 50005，仅接受 `172.16.0.10` 的 GET/APPLY/SAVE/RELOAD 与遥测订阅 |
| 固件升级 | UDP 50006，仅接受来自 `172.16.0.10` 的签名 OTA |

UDP 50002 同时识别 V2 与上一版 A5 V1 控制帧；其他命令服务只接受 V2。
V1 只开放可无歧义映射到当前安全域的继电器子集。行驶量已由百分比改成有物理
单位的 `valve_current_target_ma`，当前 PCB 又没有 ECU 可验证的转角反馈，因此
非零旧油门或旧转向请求都会拒绝整帧，绝不做隐式换算。

非紧急 V1/V2 控制只接受遥控器 `172.16.0.9`、固定调试机 `172.16.0.10` 和本设备
域控 `172.16.0.12`；调参、遥测订阅、工厂服务及 OTA 仍只接受 `.10`。同一
`sender_id` 的活动会话还绑定首次接受的源地址，所以三个控制端必须使用不同
`sender_id`，其他源不能续租、RELEASE 或清故障。结构和校验完整的网络急停仍在
源地址、sequence 和其他
执行字段语义之前主导，以免访问控制阻止安全停车。这个例外也意味着不可信网络
上的攻击者可造成拒绝服务，因此物理网络隔离仍是强制要求。
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

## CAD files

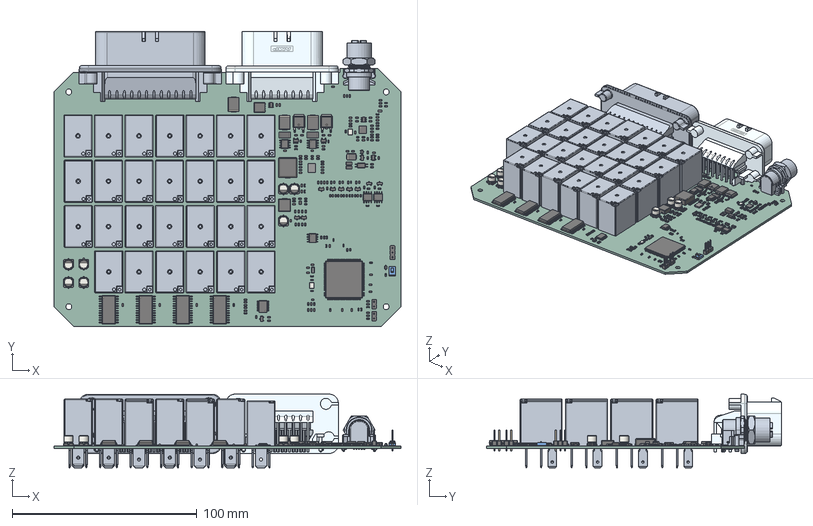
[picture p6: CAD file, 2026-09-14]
pcb/roller/ecu/PROJECT1.step
187.6 x 159.6 x 39.9 mm
LED_0603_1608Metric x 4
TDSON_8_1
CP_Elec_5x54 x 7
R_0603_1608Metric x 95
Crystal_SMD_3225-4Pin_3.2x2.5mm x 2
C_0603_1608Metric x 78
932d09b3-9c39-11ed-93f0-dde97e994e83_part x 2
932d09b4-9c39-11ed-93f0-dde97e994e83_part x 2
932d09b5-9c39-11ed-93f0-dde97e994e83_part x 2
100008F00583ukst x 18
Texas_RGE0024H_VQFN-24-1EP_4x4mm_P0.5mm_EP2.7x2.7mm
SOT-23-5 x 3
D_SOD-323
D_SMC x 3
HFV6_2__stp x 9
SOIC-24W_7.5x15.4mm_P1.27mm x 4
D_SOD_523 x 4
R_1206_3216Metric x 2
C-776163-1
SOT-23 x 9
Pins
SOT-23-6 x 2
L_APV_APH0630
L_0805_2012Metric
SS-12400-004_PART1
SS-12400-004_PART2
SS-12400-004_PART3
L_APV_APH1040
R_2512_6332Metric x 2
零件4
TSSOP-20_4.4x6.5mm_P0.65mm
PinHeader_1x02_P254mm_Vertical x 2
D_SMB
SW_SPST_EVQPE002
SW_SPST_EVQPE1
SOIC-8_3.9x4.9mm_P1.27mm x 5
Crystal_SMD_3215-2Pin_3.2x1.5mm
C-776087-1
SOT-323_SC-70
PinHeader_1x03_P254mm_Vertical
SOP-4_4.4x2.6mm_P1.27mm
LQFP-144_20x20mm_P0.5mm
PROJECT1_PCB

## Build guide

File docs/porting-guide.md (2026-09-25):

# Understanding a new machine integration

[Architecture](architecture.md) · [Interfaces](interfaces.md) · [Safety](SAFETY.md)

Begin with the machine's existing functions and control paths. Choose the
electrical interface after understanding the mechanical result it can produce.

## 1. Inventory the functions

List steering, propulsion, braking, direction/transmission, work actuators,
lights, horn, manual controls, interlocks, and sensors. Identify which functions
can already be controlled electrically and which would need an added actuator.

## 2. Make an interface table

Record one row per function. The examples below are conceptual, not wiring
instructions for a particular machine.

| Function | Possible interface | Useful feedback | Questions to resolve |
| --- | --- | --- | --- |
| Steering | Motor drive, CAN, electrohydraulic input | Angle/position, actuator state | Direction, travel limits, torque, manual coexistence |
| Propulsion | Proportional valve, analog command, CAN | Speed, current, pressure, drive state | Neutral, direction, braking interaction, loss of command |
| Auxiliary | Relay/contact, discrete output, CAN | Original switch or load state | Contact topology, polarity, load current, default state |

Distinguish a command interface from a measurement interface. A speed pulse is
feedback, not a speed command; a valve-current loop is not automatically a
vehicle-speed controller.

## 3. Define state and units

Write down physical units, ranges, signs, scaling, and freshness. Decide how
unknown or stale feedback is represented. Identify which original switches and
interlocks must be observed, and which outputs need independent confirmation.

## 4. Define each transition

Describe startup, enable, manual takeover, direction changes, stop, fault reset,
and communication loss. For every output, specify reset, power-loss, invalid-command,
watchdog, and emergency-stop states. Include retained energy and mechanical
effects in that reasoning.

## 5. Map the interface in code

Reuse command framing, validation, and state representation where they fit.
Keep machine wiring, raw bus messages, scaling, and calibration in identifiable
mapping code. A small explicit mapping is often easier to study than a new
framework. Follow the source paths in the [firmware guide](firmware.md).

## 6. Explore the physical behavior gradually

For an actual installation, start with isolated inputs and dummy loads. Move to
controlled, low-energy commissioning one actuator at a time. Establish the
low-level behavior before adding upper-level autonomy. Record the exact board,
wiring, load, and assumptions associated with any observation.

The source examples provide an engineering starting point; each machine still
needs its own electrical, hydraulic, mechanical, and safety decisions.

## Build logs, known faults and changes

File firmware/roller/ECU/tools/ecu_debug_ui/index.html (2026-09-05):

ROLLER ECU // V2电流闭环台架与参数标定

等待 ECU

IDLE

操作前确认车辆可靠支撑且执行器动作安全。普通断链、控制超时和阀局部故障会令所有自动控制输出归零，但在 ATECC/MCU 认证及实体急停输入健康时保留 K12 人工驾驶许可；网络急停、实体急停或 Secure 关键故障会断开 K12。网页急停不能替代实体急停。

## 连接与控制权

ECU IPv4应用

发送方

仲裁优先级数值越大越优先；255 保留给急停

启用控制（V2，20 Hz）

目标归零释放控制权清除锁存故障

浏览器心跳中断 1 s 后，后端主动发送释放帧。固件命令超时为 300 ms。

紧急停止

## 前进 / 后退阀电流目标

反向 ← 0 → 前进0 mA归零

正值驱动前进阀，负值驱动后退阀；绝对值小于 50 mA 作为零目标。换向会先降至零、确认电流消退，再执行死区切换。

请求目标—

施加目标—

阀状态—

前进反馈—

反向反馈—

前/反占空比—

## CAN2 转向电机 · 开环角速度

速度幅值0.6 °/s

转向使能（先确认车辆架空）等待支持角速度模式的 ECU

按住：负方向STOP按住：正方向

请求角速度—

已确认命令角速度（非反馈）—

速度命令—

电机速度反馈（原始）—

状态 / 总线—

使能确认 / 回包—

故障 / 计数—

本硬件没有转角传感器，ECU 不执行角度闭环或机械限位。“已确认命令角速度”只是最近一次速度 SDO ACK 对应的命令值，不是实测角速度或转角，严禁作为上位角闭环反馈。电机参数 0002 按本型号额定 80 rpm 标定，命令显示为额定转速千分比；心跳速度仅按厂商定义显示原始有符号值。正值沿用旧版“转角增大”方向；人工按钮必须按住，单次最多 2 s，松开、页面失焦或通信超时立即归零。本页风险确认、loopback/CSRF 与源 IP 仅定义本机台架信任域，不是操作员身份认证。

## 车辆许可与档位

K11 驻车控制

### 龟兔档

乌龟 · K14 悬空兔子 · K14 接 GND

有效控制时 K13 接管原车信号；释放控制后 K13 恢复原车。

## 发动机

按住启动（最长 3 s）

### 高 / 低转速一次触发

低中止高

仅切换时 K3 切断原车；K24（BAT/高）或 K25（GND/低）闭合 1 s 后释放，随后 K3 恢复。

## 振动继电器

### 振幅

停止大振小振

### 位置

前振后振

使能和大/小、前/后均由两级继电器接管；释放控制恢复原车线路。

## 泵与声光

### 水泵

关闭泵 1泵 2

### 灯光

前主灯后主灯前 LED后 LED

### 声光

喇叭倒车蜂鸣左转右转

## 车辆状态与传感器

车速—

发动机转速—

发动机信号—

水位 ADC—

油温 ADC—

油位/油压 ADC—

J1939 水温—

J1939 油压—

状态周期—

## 安全诊断

本机急停发送—

网络急停锁存—

实体急停输入—

K12 运行许可命令—

Secure 关键抑制—

ATECC608C—

安全芯片序列号—

配置 / 数据锁—

启动身份认证—

MCU UID—

请求继电器命令—

施加继电器命令—

K12 状态是 TPIC 输出命令，不是继电器触点反馈；本版 PCB 未布置 K12 触点反馈。

阀故障—

丢样—

先“实时应用”到 RAM 并从低电流逐步验证；确认后释放控制并“保存到 Flash”。2.5 A 快速过流、2.2 A 持续过流等硬限制不可由 UI 修改。

## 在线电流目标

启用零目标控制（V2，20 Hz）等待 1 kHz 遥测归零并释放控制权

反向 ← 0 → 前进0 mA立即归零

请求目标—

施加目标—

阀状态—

前进反馈—

反向反馈—

前/反占空比—

进入本页后，目标输入会等待首批新鲜 1 kHz 样本再解锁，确保目标阶跃发生前波形已开始采集。暂停波形或遥测超时会锁定非零输入；“立即归零”始终可用。启用本页控制时先强制全部目标归零，不会恢复切页前的潜在动作。

## 1 kHz 实时波形（10 s）

请求目标斜坡目标带符号反馈

前进占空比反向占空比

暂停波形清空导出 CSV打开本页并保持可见时才启用 1 kHz 遥测

## PI 与标定参数

活动版本 —Flash 代次 —状态 —来源 —

参数 | 前进阀 | 后退阀 | 允许范围 / 单位

读取 ECU载入默认值实时应用（RAM）撤销并重载 Flash释放控制并保存 Flash

实时应用不写 Flash。保存时先释放控制；ECU 仅在两阀电流低于 50 mA、PWM 为零且输出未武装时写入，10 s 内重复保存会被拒绝。

OTA 前必须按下并持续保持实体急停，使 Secure ESTOP_DETECT 保持有效；升级开始后 ECU 隔离全部输出，完成外层签名/SHA-256 校验后重启，OEMiROT 再次验证并解密成对镜像。实体急停须保持到新镜像确认完成。

## 签名加密固件升级

升级包校验并升级

阶段IDLE

版本—

进度0%

仅接受由产品 OTA 传输私钥签名、与当前 Flash 布局完全一致、Secure/NonSecure 成对且经过 OEMiROT 加密的包。按住实体急停并保持到交换及镜像确认完成；上传期间禁止车辆作业和断电。

## 设备绑定状态

启动认证—

配置区—

数据区—

配对代次—

量产要求：ATECC 配置/数据区和私钥 Slot 锁定，MCU UID、ATECC 序列号、公钥及配置 CRC 均与安全清单一致。

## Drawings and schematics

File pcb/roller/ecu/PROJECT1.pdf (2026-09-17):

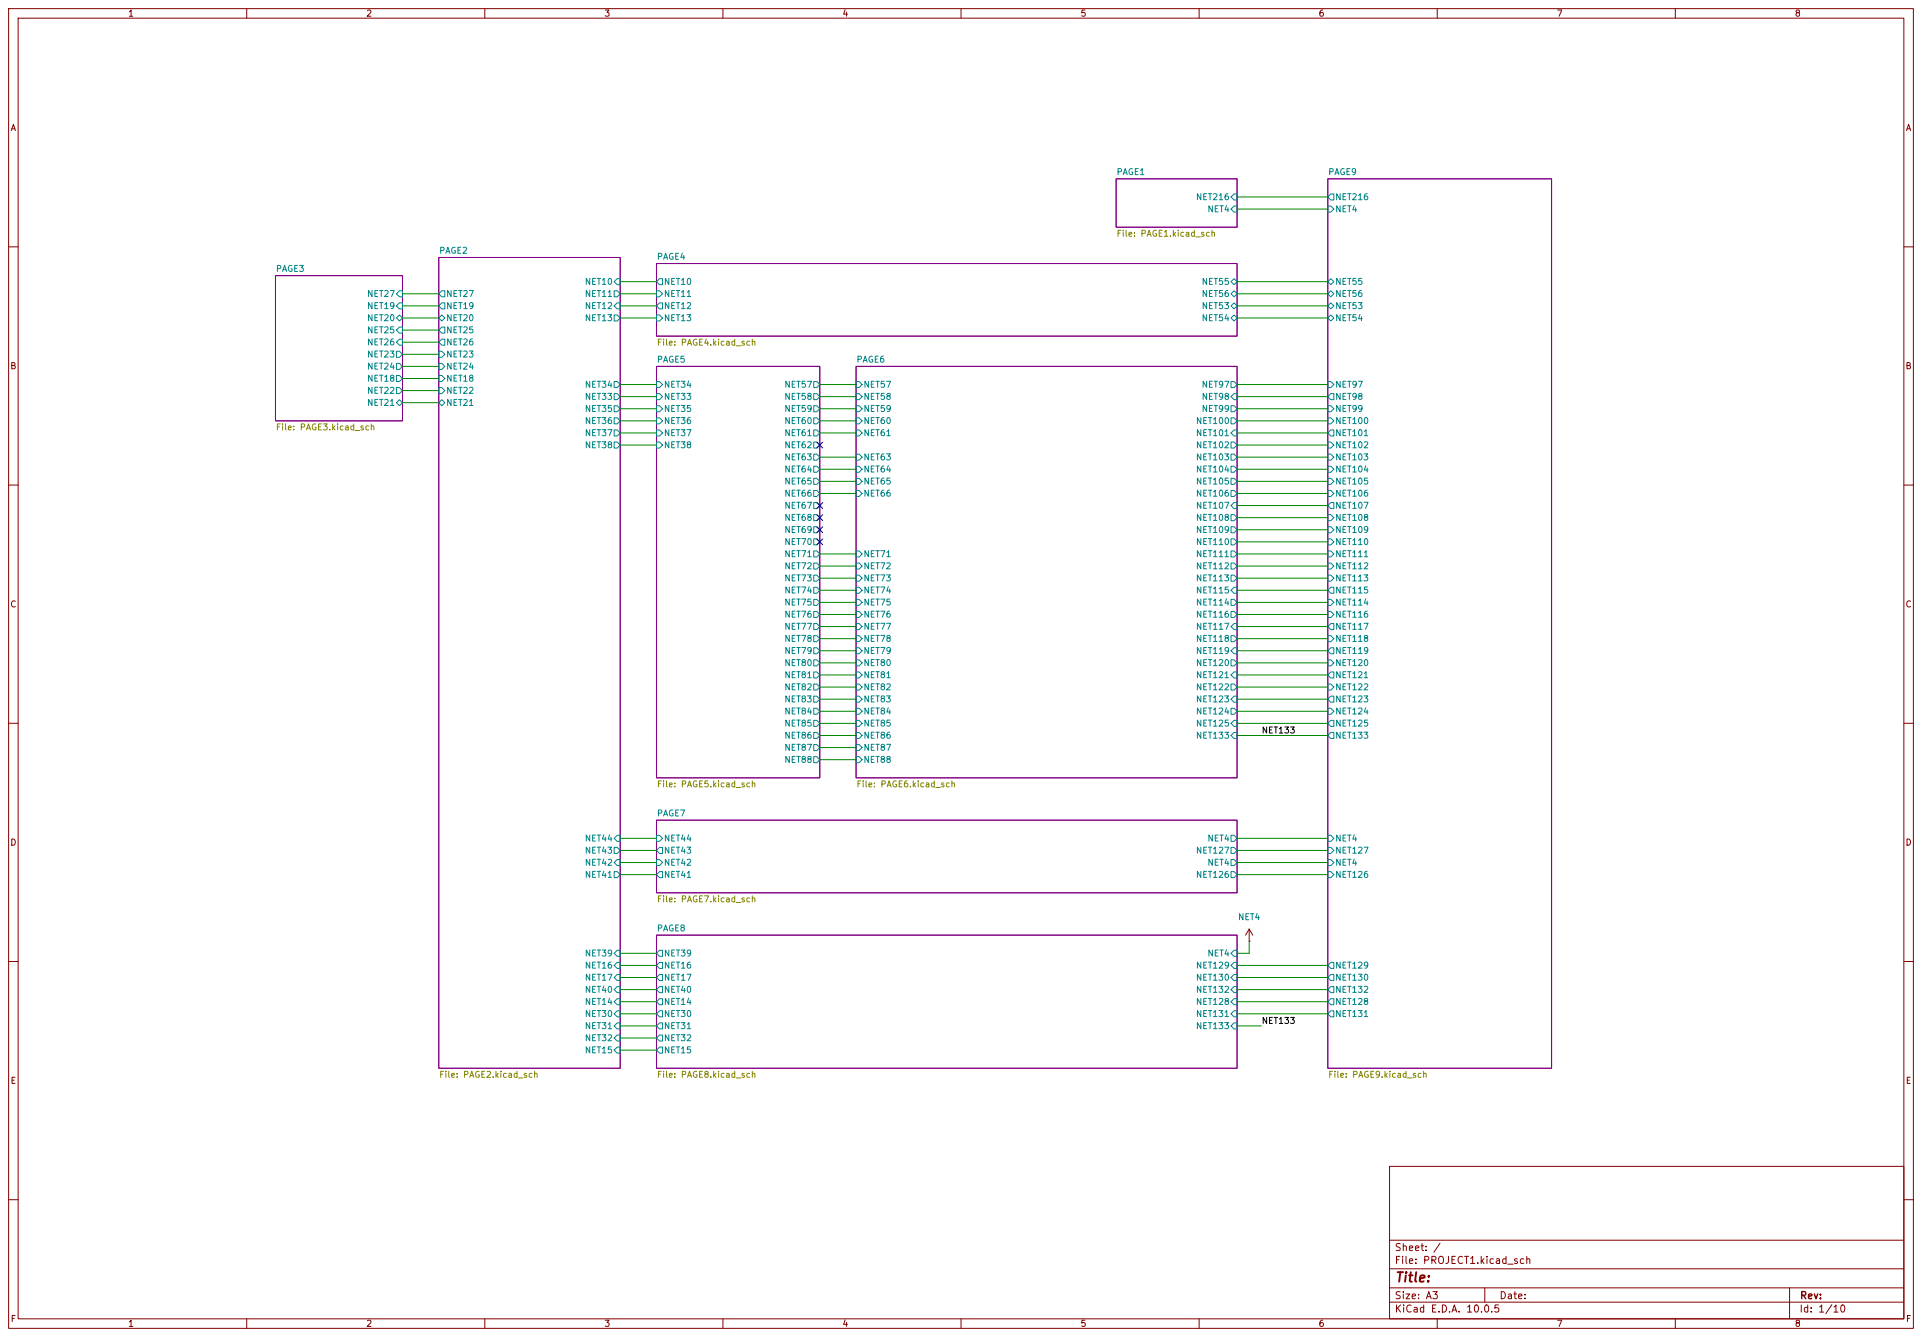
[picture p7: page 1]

Size: A3 | Rev: | F Date:
KiCad E.D.A. 10.0.5 | Id: 1/10

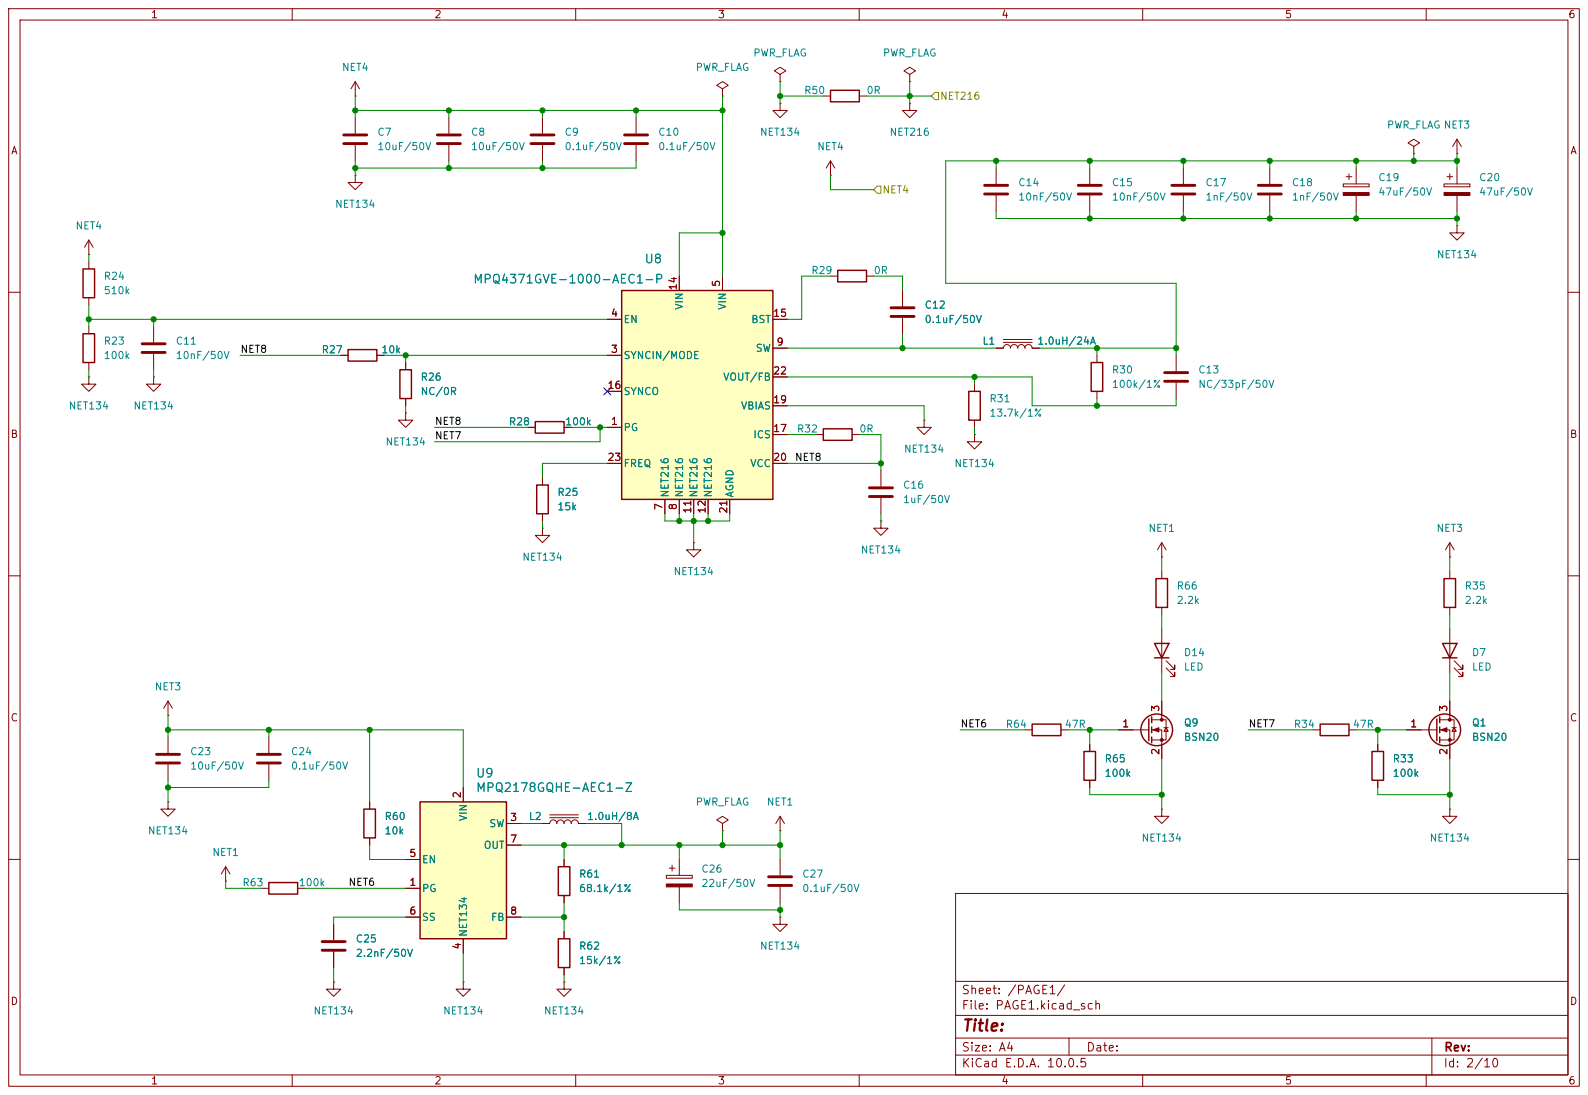
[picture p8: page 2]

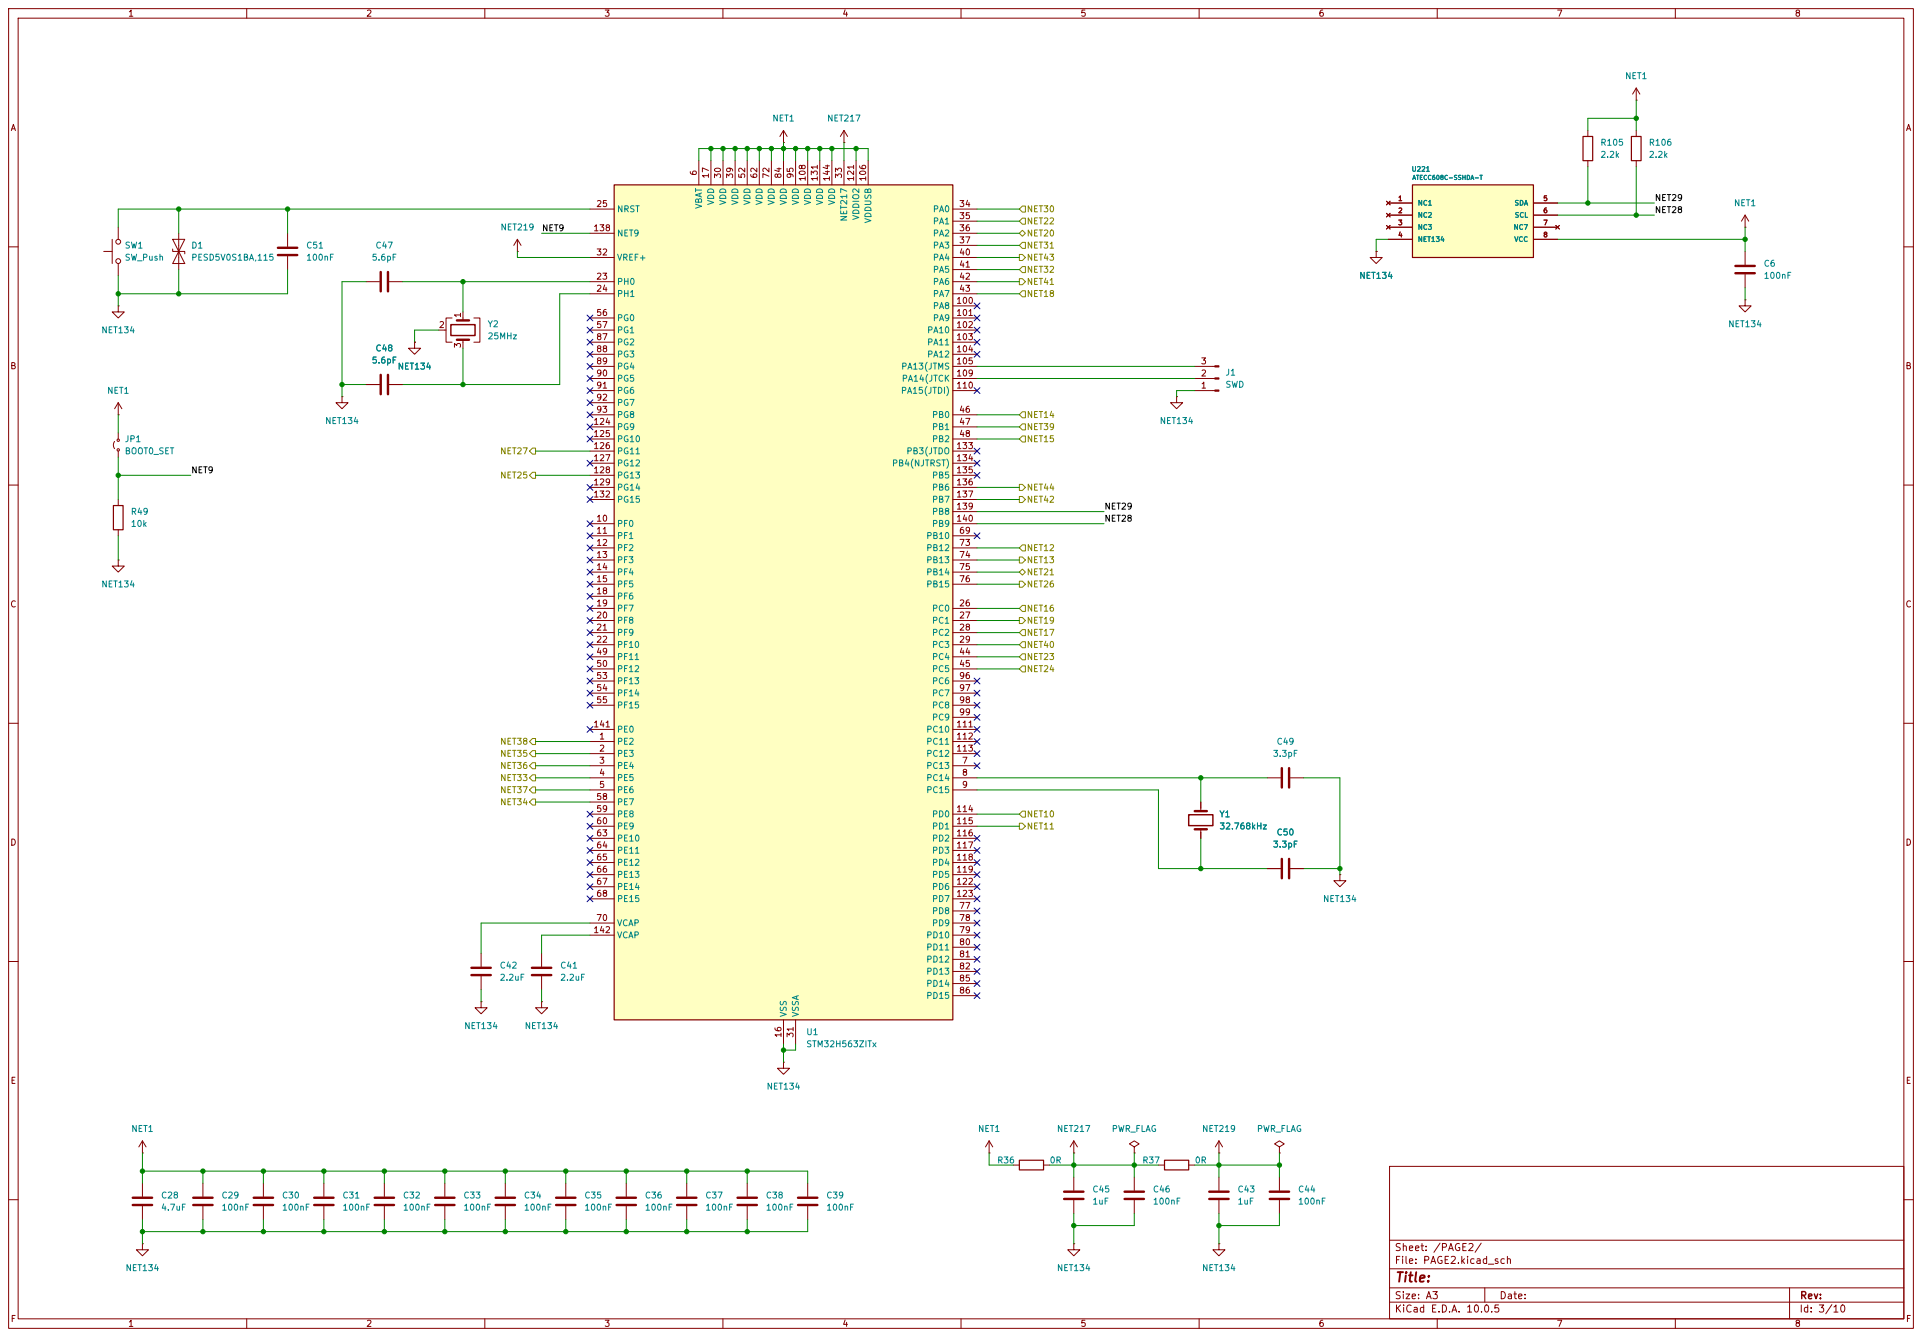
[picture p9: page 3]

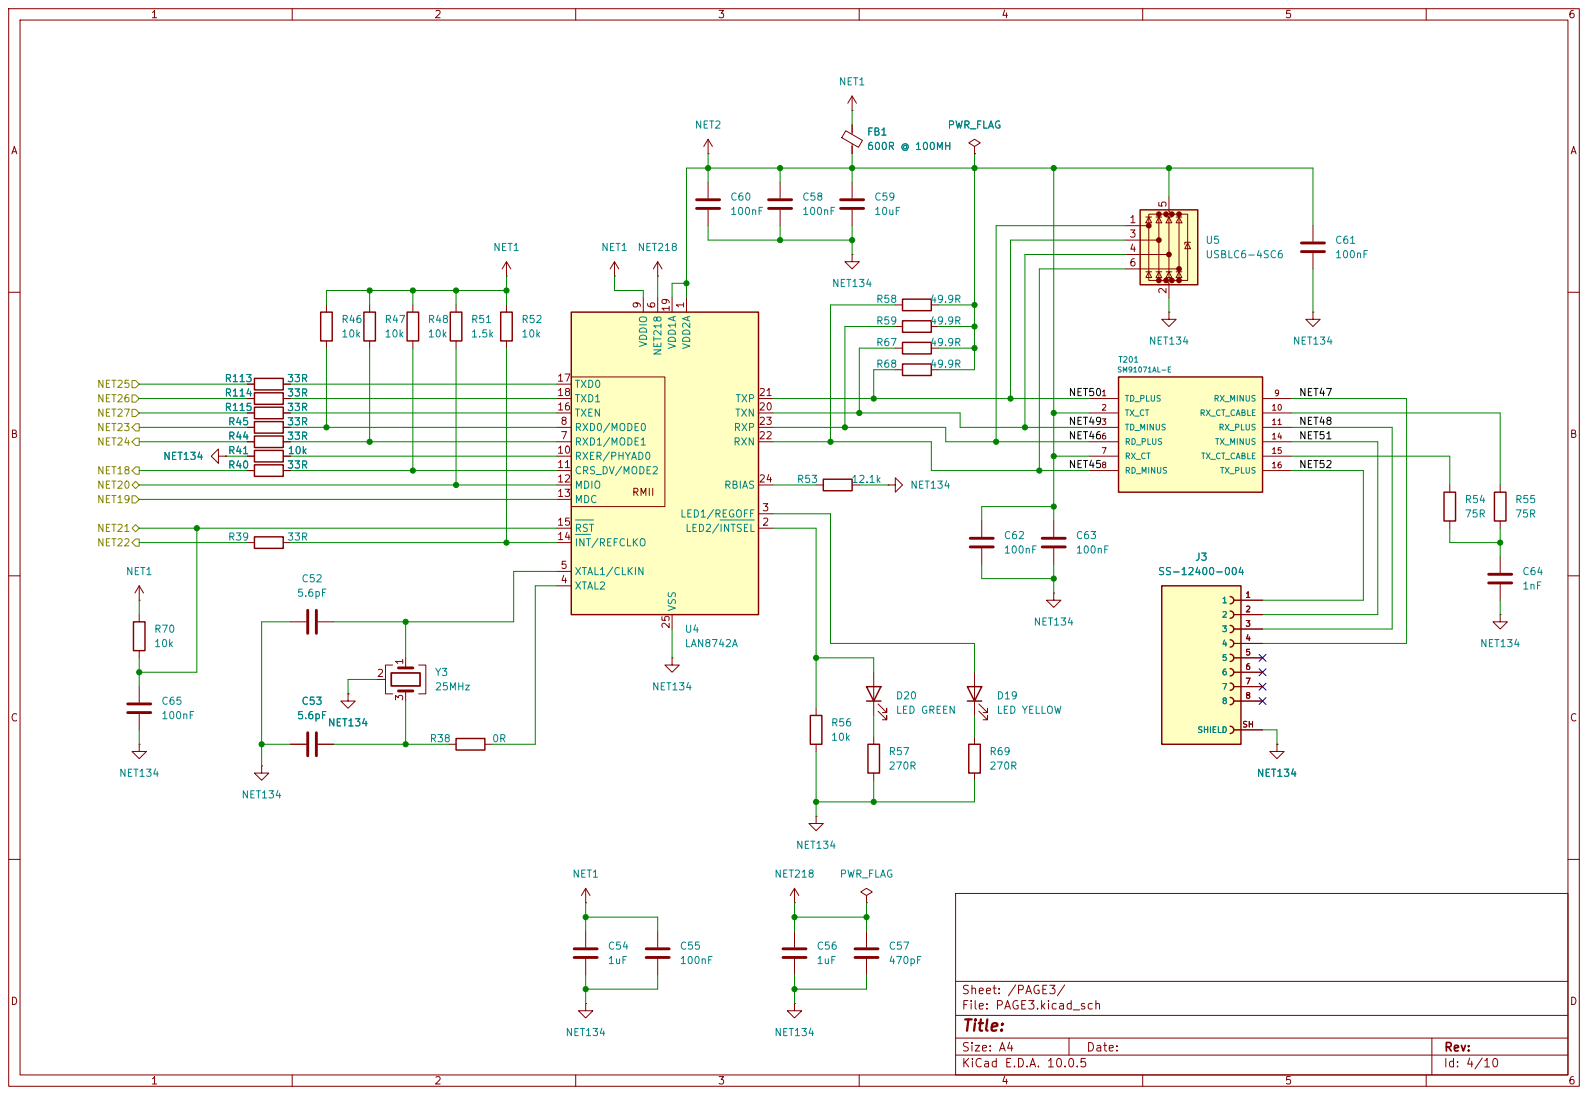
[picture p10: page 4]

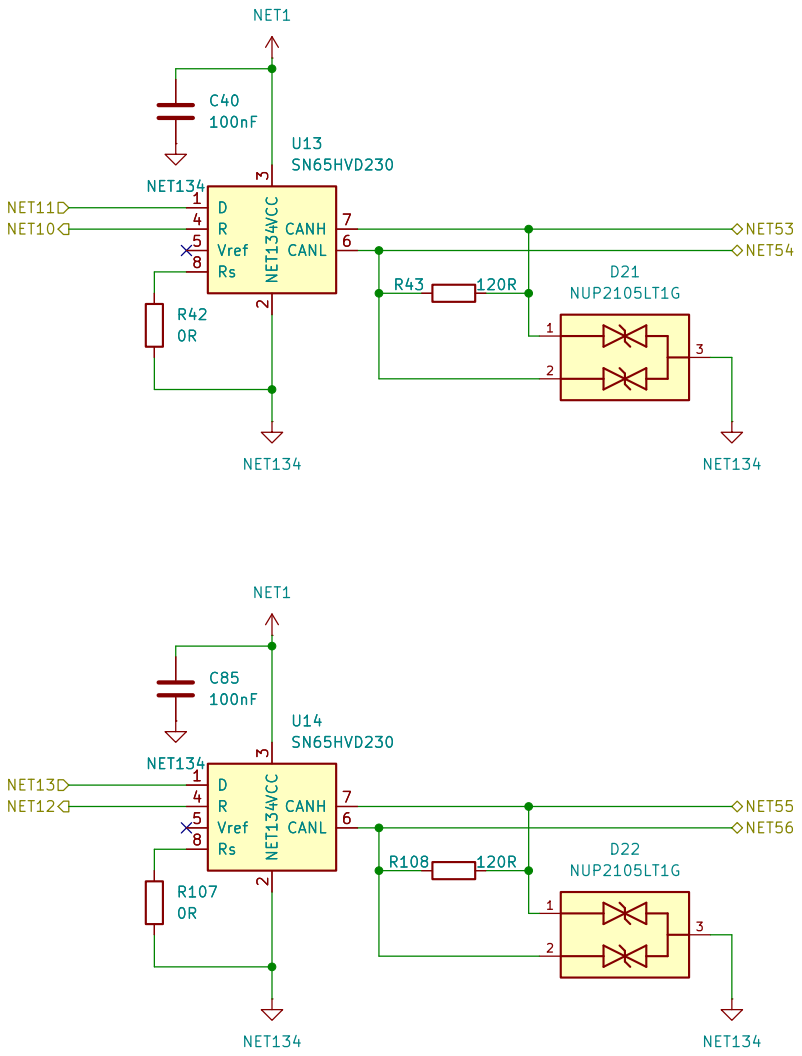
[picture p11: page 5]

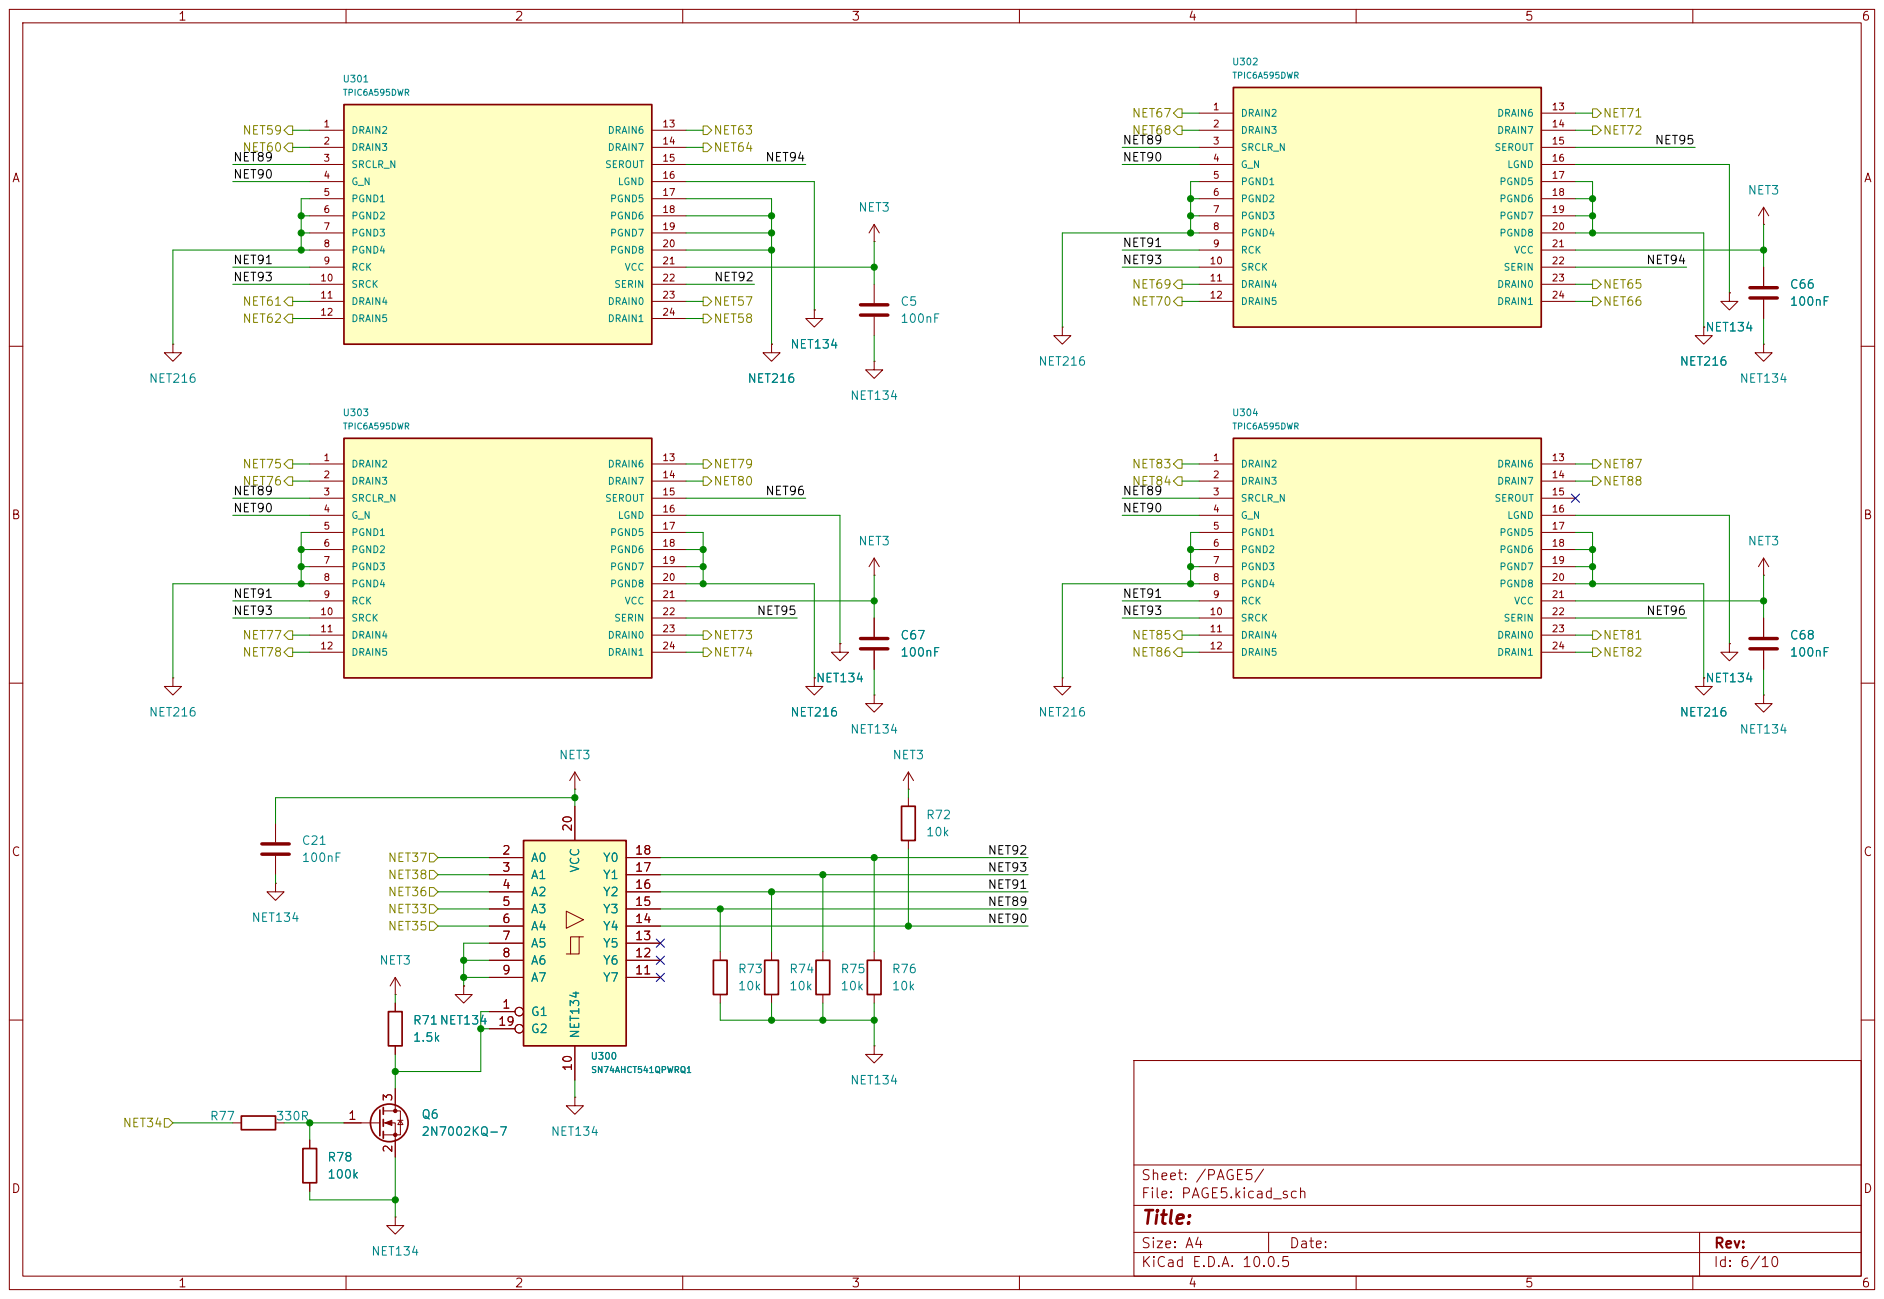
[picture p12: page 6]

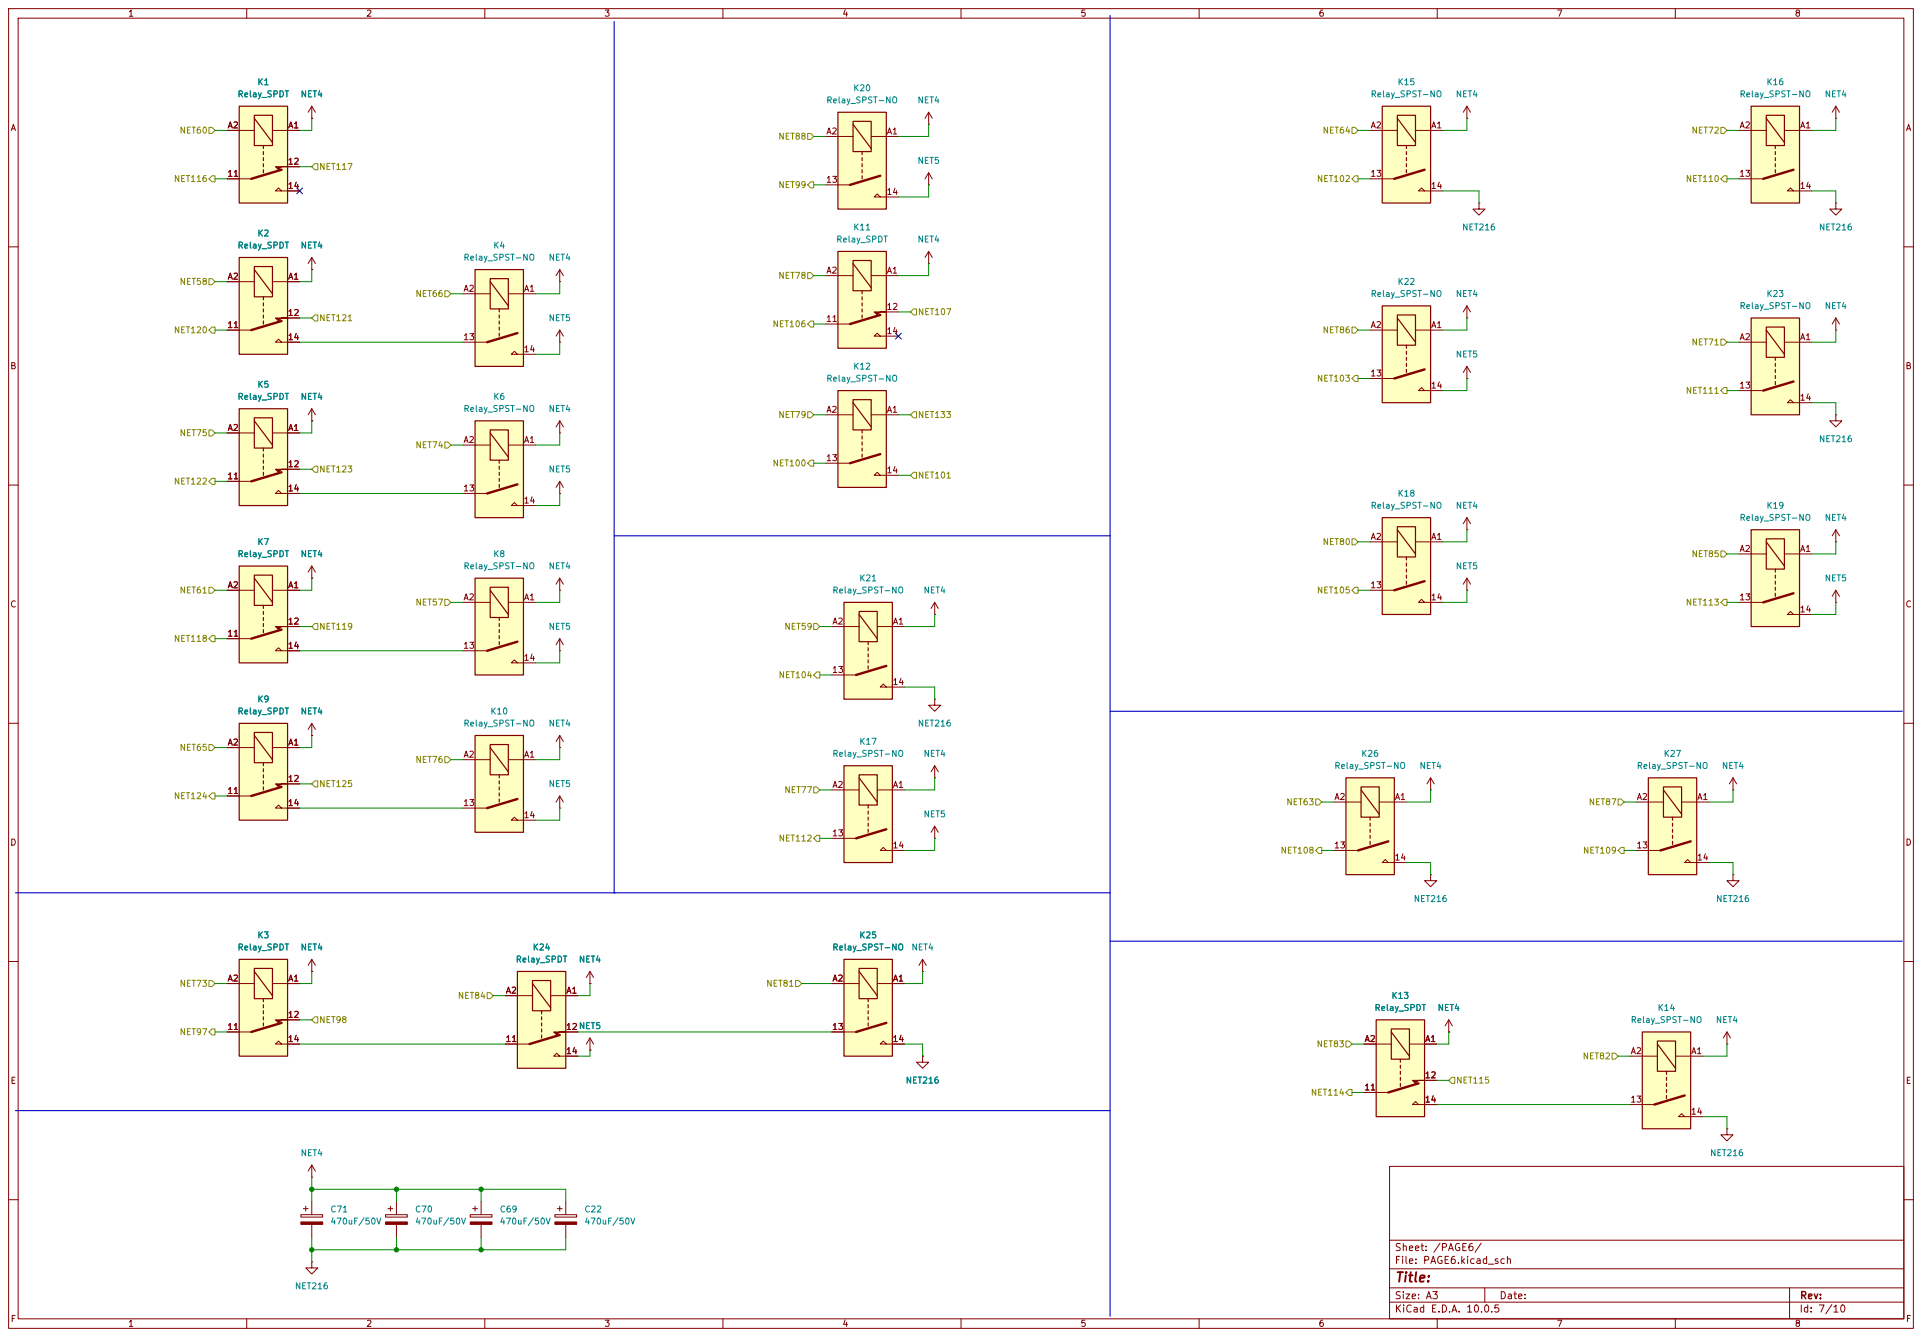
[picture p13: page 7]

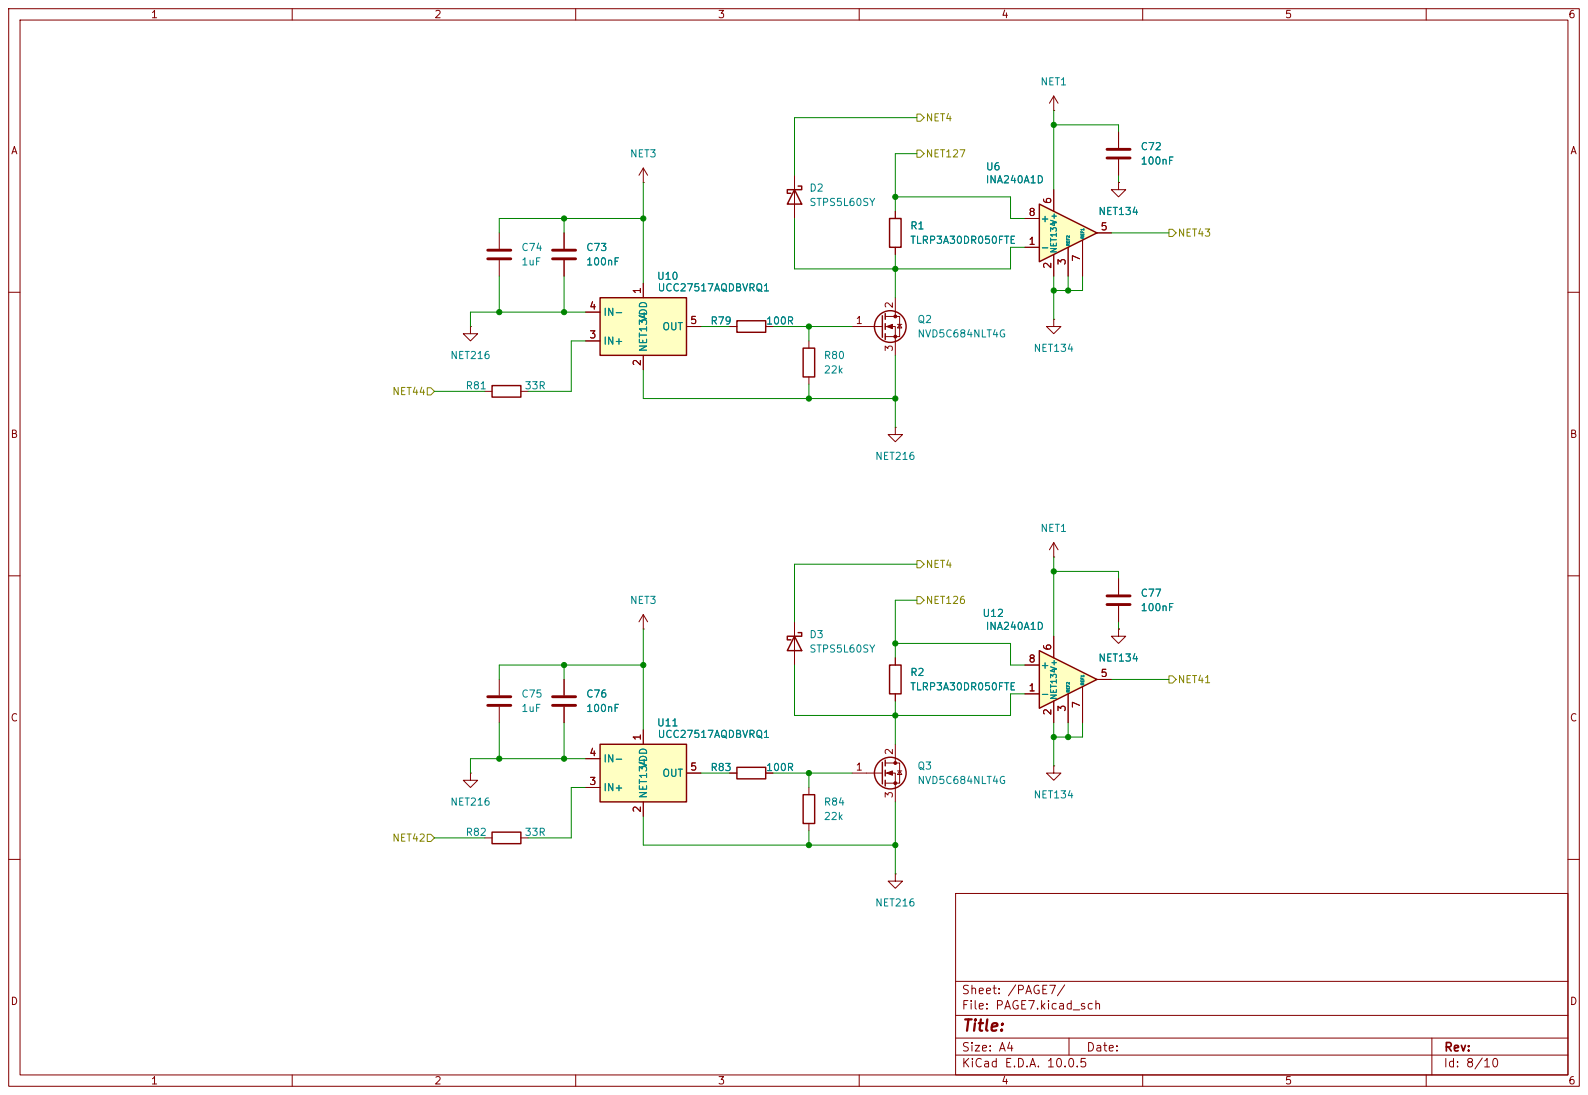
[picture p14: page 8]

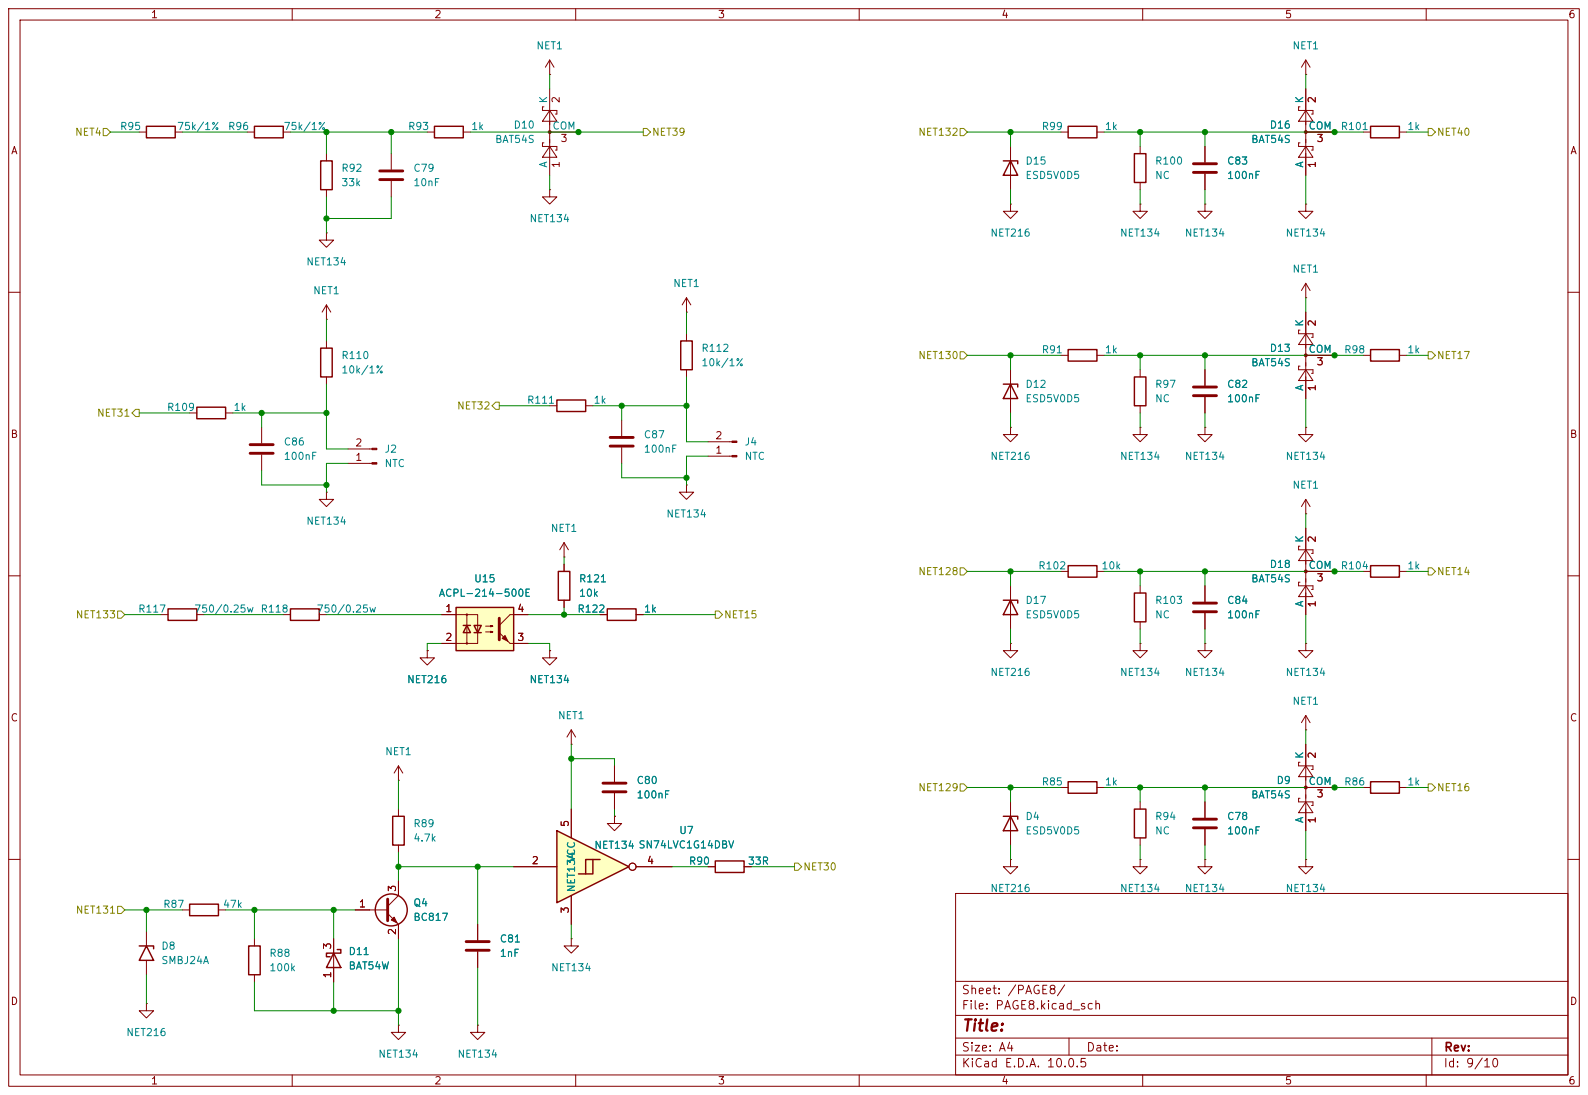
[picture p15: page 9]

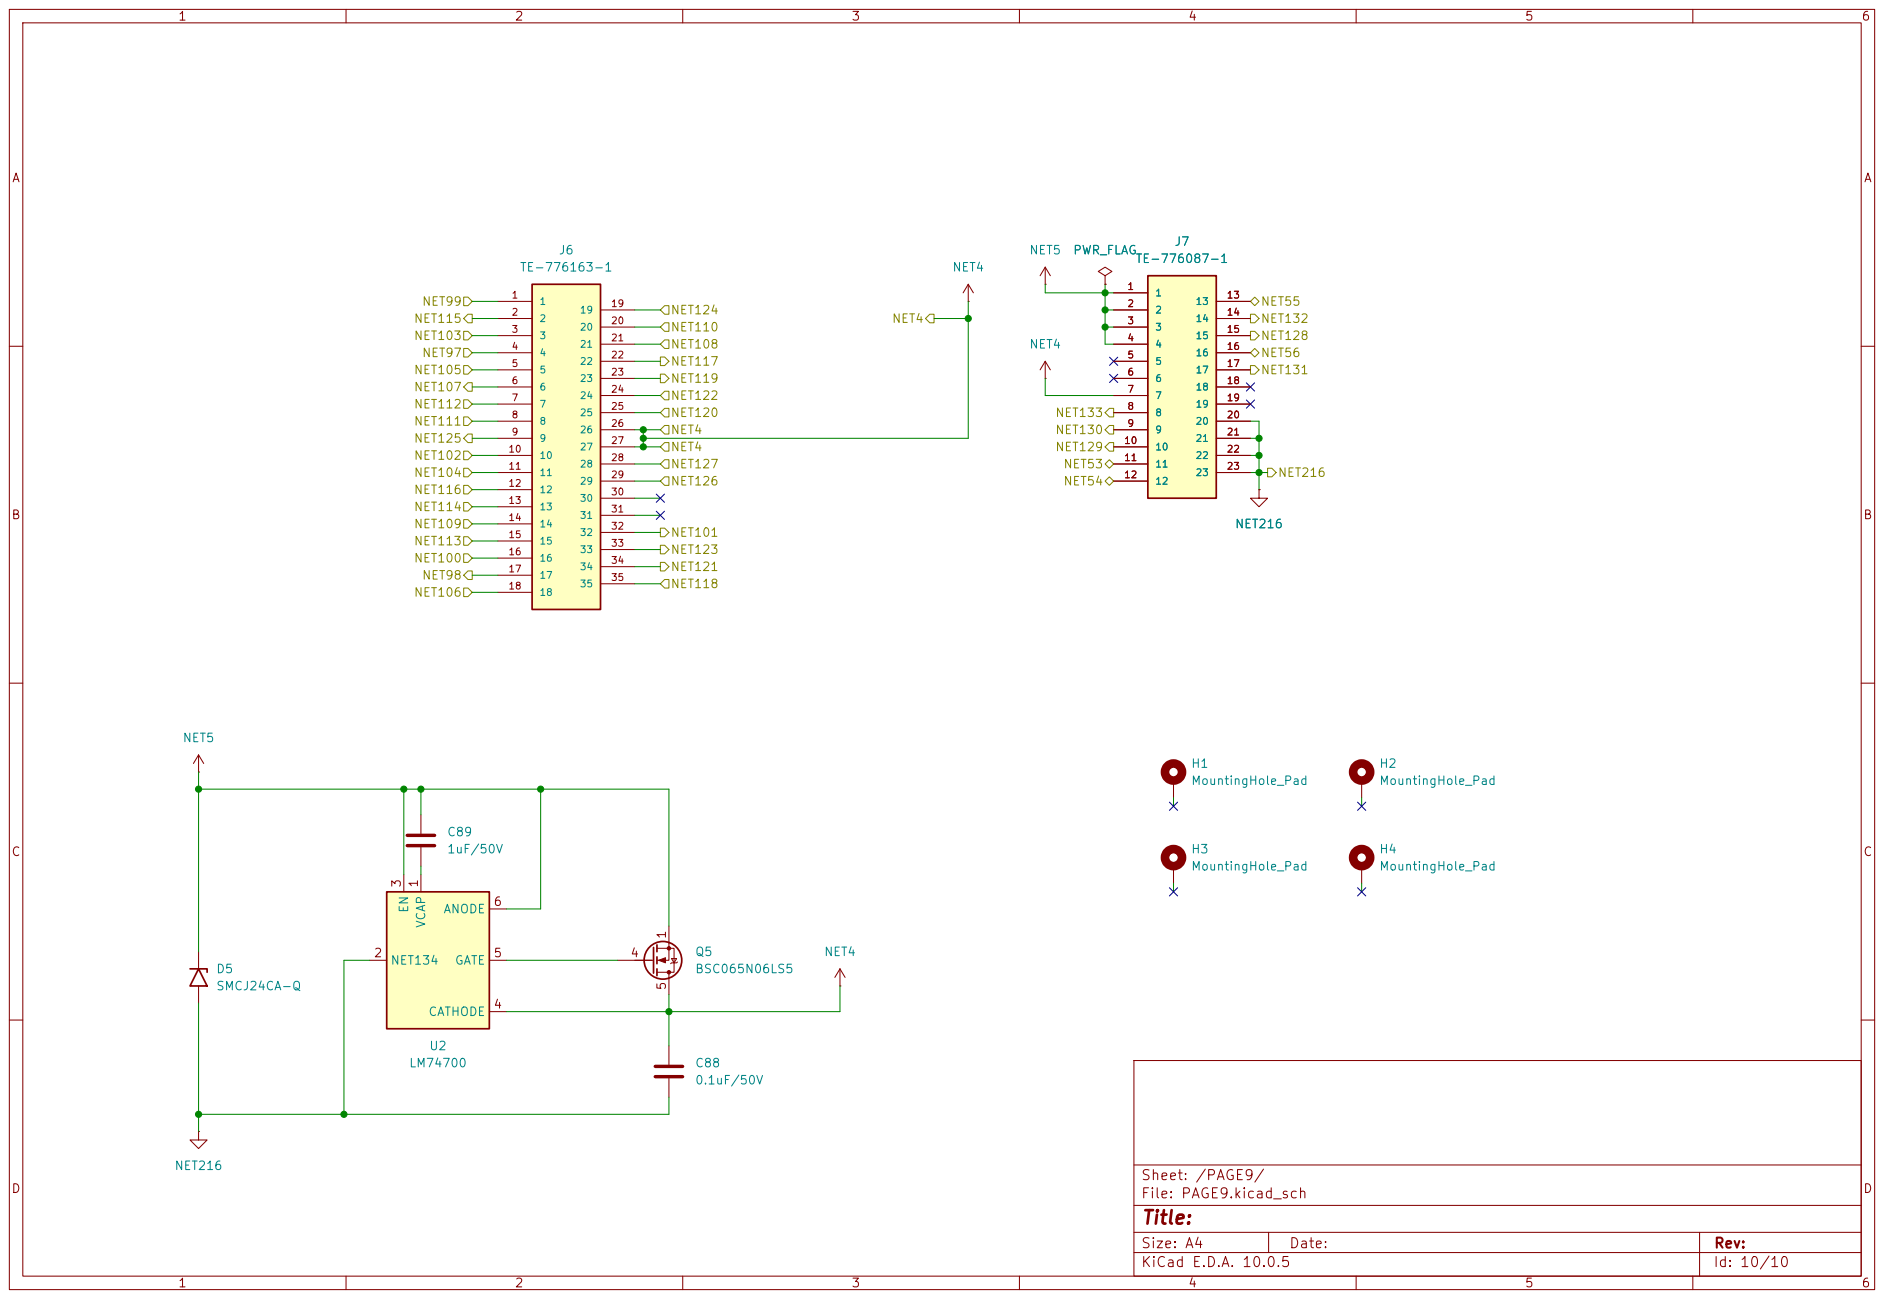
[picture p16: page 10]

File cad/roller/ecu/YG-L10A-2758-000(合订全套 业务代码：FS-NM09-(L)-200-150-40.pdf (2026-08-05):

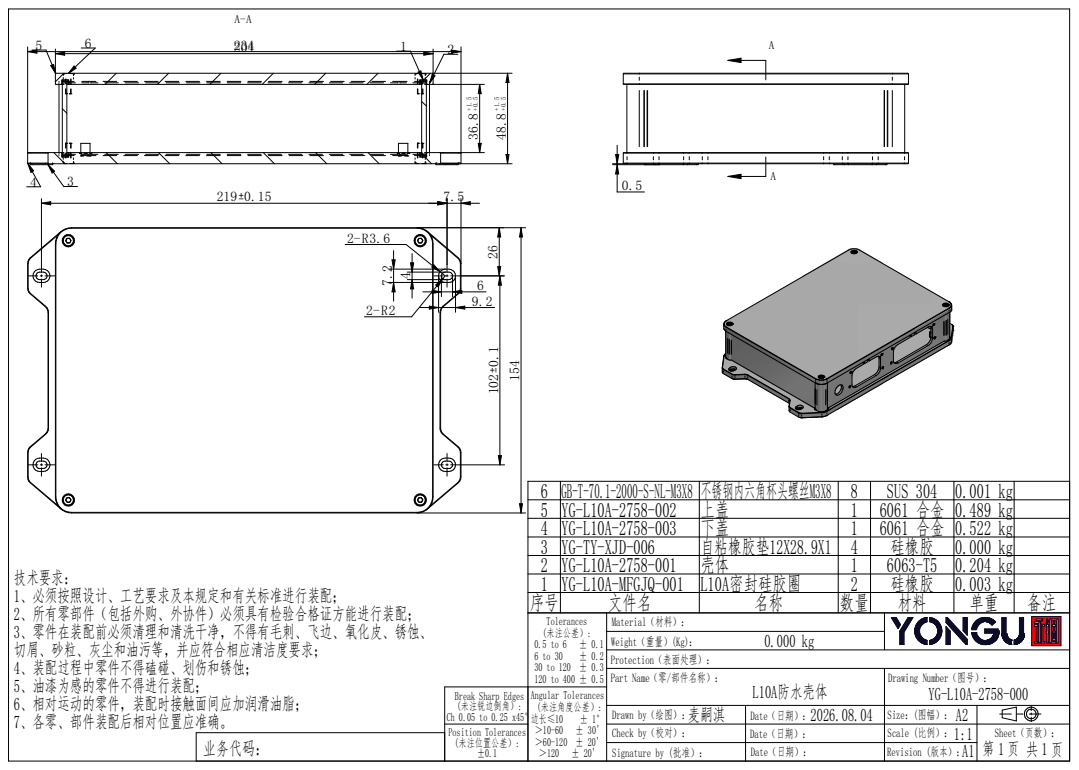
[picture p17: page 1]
Angular Tolerances (未注角度公差）:; ＞60-120 ± 20' 业务代码：

6 | GB-T-70.1-2000-S-NL-M3X8 | 不锈钢内六角杯头螺丝M3X8 | 8 | SUS 304 | 0.001 kg
5 | YG-L10A-2758-002 | 上盖 | 1 | 6061 合金 | 0.489 kg
4 | YG-L10A-2758-003 | 下盖 | 1 | 6061 合金 | 0.522 kg
3 | YG-TY-XJD-006 | 自粘橡胶垫12X28.9X1 | 4 | 硅橡胶 | 0.000 kg
2 | YG-L10A-2758-001 | 壳体 | 1 | 6063-T5 | 0.204 kg
1 | YG-L10A-MFGJQ-001 文件名 | L10A密封硅胶圈 名称 | 数量 2 | 硅橡胶 材料 | 0.003 kg 序号 单重 | 备注

技术要求：
1、必须按照设计、工艺要求及本规定和有关标准进行装配；
2、所有零部件（包括外购、外协件）必须具有检验合格证方能进行装配；
3、零件在装配前必须清理和清洗干净，不得有毛刺、飞边、氧化皮、锈蚀、
切屑、砂粒、灰尘和油污等，并应符合相应清洁度要求；
4、装配过程中零件不得磕碰、划伤和锈蚀；
5、油漆为感的零件不得进行装配；
6、相对运动的零件，装配时接触面间应加润滑油脂；
7、各零、部件装配后相对位置应准确。

Tolerances (未注公差）: 0.5 to 6 ± 0.1 6 to 30 ± 0.2 30 to 120 ± 0.3 120 to 400 ± 0.5 | Material（材料）：

Weight（重量）(Kg)：
Protection（表面处理）：

Part Name（零/部件名称）： L10A防水壳体 | Drawing Number（图号）： YG-L10A-2758-000

Break Sharp Edges
(未注锐边倒角）:

麦嗣淇 Drawn by（绘图）： | 2026.08.04 Date（日期）： | A2 Size：(图幅）：

Position Tolerances (未注位置公差）: ±0.1 | | Check by（校对）： | Date（日期）： | 1:1 Scale (比例）： | Sheet（页数）： 第 页1 共 页1

Signature by (批准）： | Date（日期）： | Revision (版本）： A1

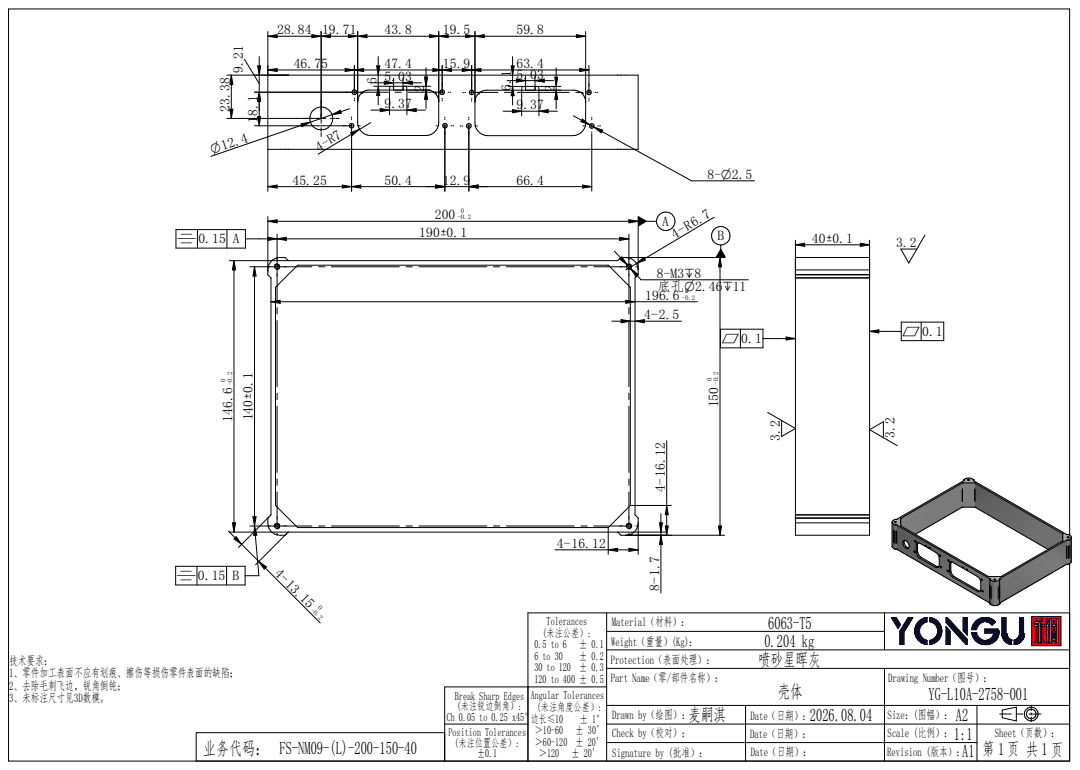
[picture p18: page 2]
Part Name（零/部件名称）：; Drawing Number（图号）：; Tolerances (未注公差）: 0.5 to 6 ± 0.1; 30 to 120 ± 0.3 120 to 400 ± 0.5 Angular Tolerances (未注角度公差）:; Date（日期）：; 6063-T5 0.204 kg 喷砂星晖灰; 技术要求： 1、零件加工表面不应有划痕、擦伤等损伤零件表面的缺陷； 2、去除毛刺飞边，锐角倒钝； 3、未标注尺寸见3D数模。; 8-M3`8 底孔O2.46`11

Material（材料）：
Weight（重量）(Kg)：
Protection（表面处理）：

Break Sharp Edges
(未注锐边倒角）:

204
190u0.1

Part Name（零/部件名称）：; Drawing Number（图号）：; Tolerances (未注公差）: 0.5 to 6 ± 0.1; 30 to 120 ± 0.3 120 to 400 ± 0.5 Angular Tolerances (未注角度公差）:; 6061 合金 0.489 kg 喷砂星晖灰; 技术要求： 1、零件加工表面不应有划痕、擦伤等损伤零件表面的缺陷； 2、去除毛刺飞边，锐角倒钝； 3、未标注尺寸见3D数模。; 周边倒角C0.3 周边倒角C0.3; 倒角C0.3

Material（材料）：
Weight（重量）(Kg)：
Protection（表面处理）：

Break Sharp Edges
(未注锐边倒角）:

Part Name（零/部件名称）：; Drawing Number（图号）：; Tolerances (未注公差）: 0.5 to 6 ± 0.1; 30 to 120 ± 0.3 120 to 400 ± 0.5 Angular Tolerances (未注角度公差）:; 6061 合金 0.522 kg 喷砂星晖灰; 技术要求： 1、零件加工表面不应有划痕、擦伤等损伤零件表面的缺陷； 2、去除毛刺飞边，锐角倒钝； 3、未标注尺寸见3D数模。; 周边倒角C0.3; 倒角C0.3; 31.2 171.6 ¹⁸.95 116.1 4-M3X5埋头压铆铝螺柱铝本色c底孔O5.1 `2.3

Material（材料）：
Weight（重量）(Kg)：
Protection（表面处理）：

Break Sharp Edges
(未注锐边倒角）:

## 3.2 全部

Tolerances (未注公差）: 0.5 to 6 ± 0.1; Date（日期）：; 硅橡胶 0.000 kg; 技术要求： 1、零件加工表面不应有划痕、擦伤等损伤零件表面的缺陷； 2、去除毛刺飞边，锐角倒钝； 3、未标注尺寸见3D数模。; 此面有不干胶

Material（材料）：
Weight（重量）(Kg)：
Protection（表面处理）：

Part Name（零/部件名称）： 自粘橡胶垫12X28.9X1 | Drawing Number（图号）： YG-TY-XJD-006

Break Sharp Edges (未注锐边倒角）: Ch 0.05 to 0.25 x45° | Angular Tolerances (未注角度公差）:

Drawn by（绘图）： | Date（日期）： | A4 Size：(图幅）：

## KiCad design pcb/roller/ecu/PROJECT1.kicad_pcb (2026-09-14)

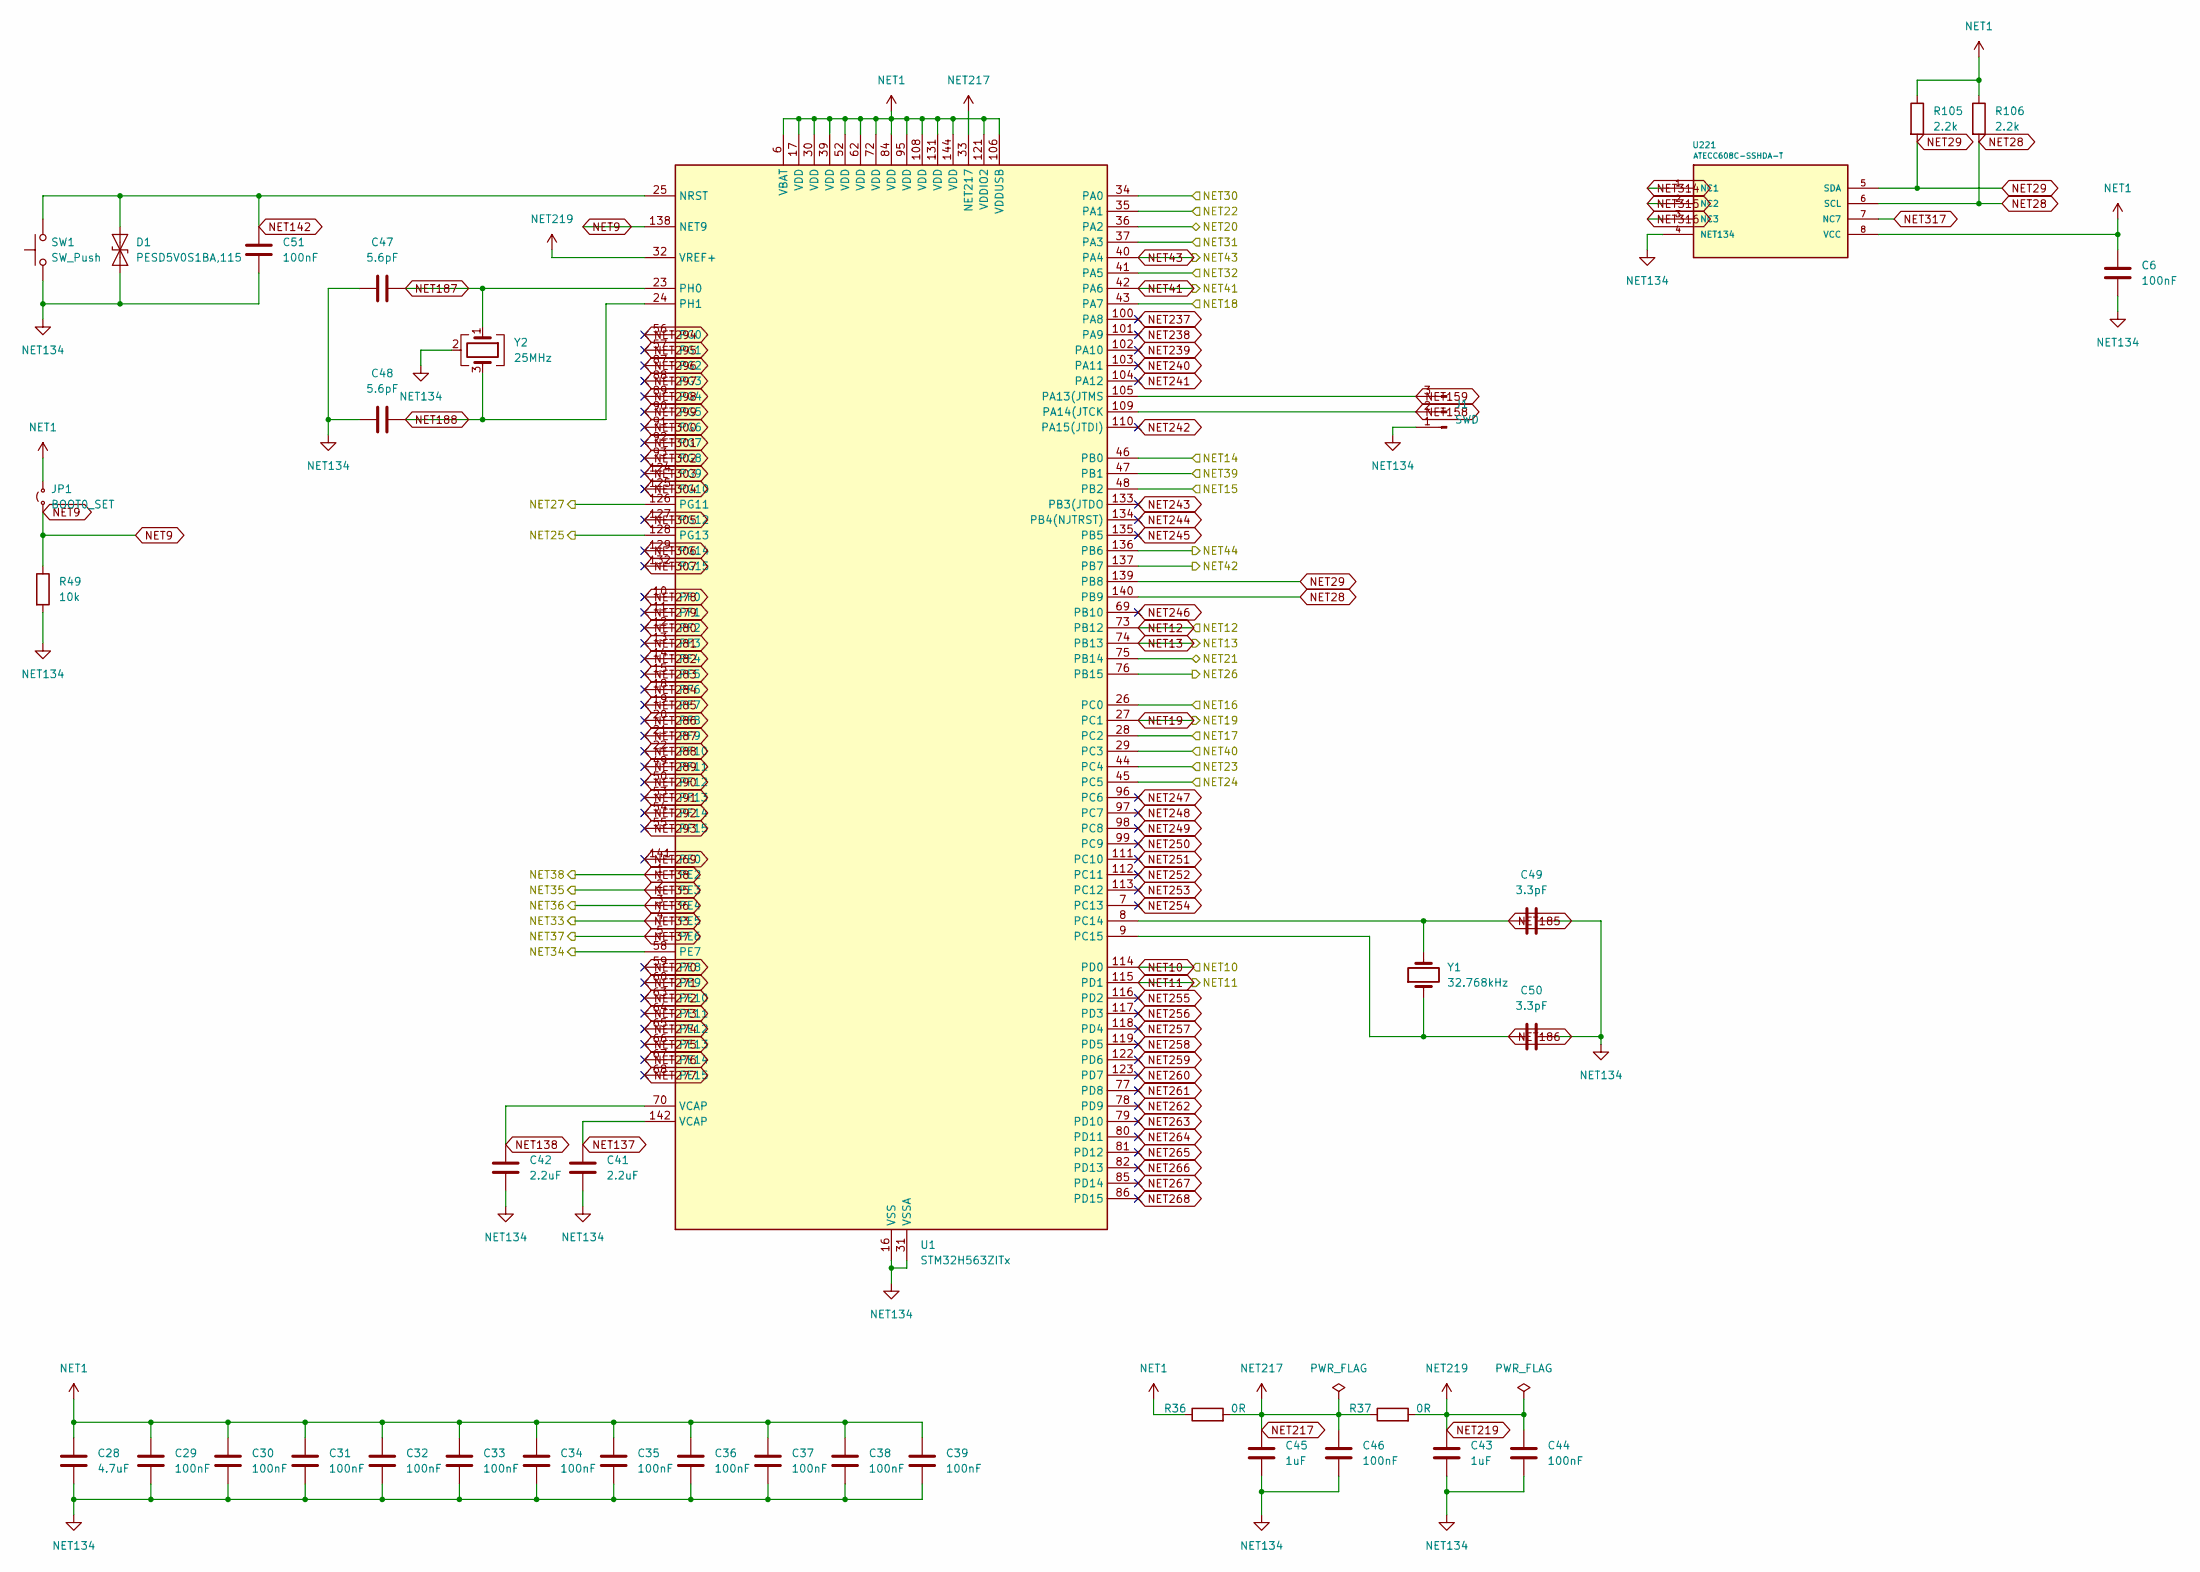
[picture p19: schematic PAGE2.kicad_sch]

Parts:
C6, C29, C30, C31, C32, C33, C34, C35, C36, C37, C38, C39, C44, C46, C51: 100nF; C_0603_1608Metric
C28: 4.7uF; C_0603_1608Metric
C41, C42: 2.2uF; C_0603_1608Metric
C43, C45: 1uF; C_0603_1608Metric
C47, C48: 5.6pF; C_0603_1608Metric
C49, C50: 3.3pF; C_0603_1608Metric
D1: PESD5V0S1BA,115; D_SOD-323
J1: SWD; PinHeader_1x03_P2.54mm_Vertical
JP1: BOOT0_SET; SolderJumper-2_P1.3mm_Open_TrianglePad1.0x1.5mm
R36, R37: 0R; R_0603_1608Metric
R49: 10k; R_0603_1608Metric
R105, R106: 2.2k; R_0603_1608Metric
SW1: SW_Push; SW_SPST_EVQPE1
U1: STM32H563ZITx; LQFP-144_20x20mm_P0.5mm
U221: ATECC608C-SSHDA-T; SOIC-8_3.9x4.9mm_P1.27mm
Y1: 32.768kHz; Crystal_SMD_3215-2Pin_3.2x1.5mm
Y2: 25MHz; Crystal_SMD_3225-4Pin_3.2x2.5mm

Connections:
NET1: C6.1, C28.1, C29.1, C30.1, C31.1, C32.1, C33.1, C34.1, C35.1, C36.1, C37.1, C38.1, C39.1, JP1.2 (B), R36.1, R105.1, R106.1, U1.6 (VBAT), U1.17 (VDD), U1.30 (VDD), U1.39 (VDD), U1.52 (VDD), U1.62 (VDD), U1.72 (VDD), U1.84 (VDD), U1.95 (VDD), U1.106 (VDDUSB), U1.108 (VDD), U1.121 (VDDIO2), U1.131 (VDD), U1.144 (VDD), U221.8 (VCC); also elsewhere on the board
NET9: JP1.1 (A), R49.1, U1.138 (BOOT0)
NET10: U1.114 (PD0); also elsewhere on the board
NET11: U1.115 (PD1); also elsewhere on the board
NET12: U1.73 (PB12); also elsewhere on the board
NET13: U1.74 (PB13); also elsewhere on the board
NET14: U1.46 (PB0); also elsewhere on the board
NET15: U1.48 (PB2); also elsewhere on the board
NET16: U1.26 (PC0); also elsewhere on the board
NET17: U1.28 (PC2); also elsewhere on the board
NET18: U1.43 (PA7); also elsewhere on the board
NET19: U1.27 (PC1); also elsewhere on the board
NET20: U1.36 (PA2); also elsewhere on the board
NET21: U1.75 (PB14); also elsewhere on the board
NET22: U1.35 (PA1); also elsewhere on the board
NET23: U1.44 (PC4); also elsewhere on the board
NET24: U1.45 (PC5); also elsewhere on the board
NET25: U1.128 (PG13); also elsewhere on the board
NET26: U1.76 (PB15); also elsewhere on the board
NET27: U1.126 (PG11); also elsewhere on the board
NET28: R106.2, U1.140 (PB9), U221.6 (SCL)
NET29: R105.2, U1.139 (PB8), U221.5 (SDA)
NET30: U1.34 (PA0); also elsewhere on the board
NET31: U1.37 (PA3); also elsewhere on the board
NET32: U1.41 (PA5); also elsewhere on the board
NET33: U1.4 (PE5); also elsewhere on the board
NET34: U1.58 (PE7); also elsewhere on the board
NET35: U1.2 (PE3); also elsewhere on the board
NET36: U1.3 (PE4); also elsewhere on the board
NET37: U1.5 (PE6); also elsewhere on the board
NET38: U1.1 (PE2); also elsewhere on the board
NET39: U1.47 (PB1); also elsewhere on the board
NET40: U1.29 (PC3); also elsewhere on the board
NET41: U1.42 (PA6); also elsewhere on the board
NET42: U1.137 (PB7); also elsewhere on the board
NET43: U1.40 (PA4); also elsewhere on the board
NET44: U1.136 (PB6); also elsewhere on the board
NET134: C6.2, C28.2, C29.2, C30.2, C31.2, C32.2, C33.2, C34.2, C35.2, C36.2, C37.2, C38.2, C39.2, C41.2, C42.2, C43.2, C44.2, C45.2, C46.2, C47.1, C48.1, C49.2, C50.2, C51.2, D1.1 (A1), J1.1, R49.2, SW1.1, U1.16 (VSS), U1.31 (VSSA), U1.38 (VSS), U1.51 (VSS), U1.61 (VSS), U1.71 (VSS), U1.83 (VSS), U1.94 (VSS), U1.107 (VSS), U1.120 (VSS), U1.130 (VSS), U1.143 (VSS), U221.4 (GND), Y2.2 (G), Y2.4 (G); also elsewhere on the board
NET137: C41.1, U1.142 (VCAP)
NET138: C42.1, U1.70 (VCAP)
NET142: C51.1, D1.2 (A2), SW1.2, U1.25 (NRST)
NET158: J1.2, U1.109 (PA14(JTCK)
NET159: J1.3, U1.105 (PA13(JTMS)
NET185: C49.1, U1.8 (PC14), Y1.2
NET186: C50.1, U1.9 (PC15), Y1.1
NET187: C47.2, U1.23 (PH0), Y2.1
NET188: C48.2, U1.24 (PH1), Y2.3
NET217: C45.1, C46.1, R36.2, R37.1, U1.33 (VDDA)
NET219: C43.1, C44.1, R37.2, U1.32 (VREF+)
NET237: U1.100 (PA8)
NET238: U1.101 (PA9)
NET239: U1.102 (PA10)
NET240: U1.103 (PA11)
NET241: U1.104 (PA12)
NET242: U1.110 (PA15(JTDI))
NET243: U1.133 (PB3(JTDO)
NET244: U1.134 (PB4(NJTRST))
NET245: U1.135 (PB5)
NET246: U1.69 (PB10)
NET247: U1.96 (PC6)
NET248: U1.97 (PC7)
NET249: U1.98 (PC8)
NET250: U1.99 (PC9)
NET251: U1.111 (PC10)
NET252: U1.112 (PC11)
NET253: U1.113 (PC12)
NET254: U1.7 (PC13)
NET255: U1.116 (PD2)
NET256: U1.117 (PD3)
NET257: U1.118 (PD4)
NET258: U1.119 (PD5)
NET259: U1.122 (PD6)
NET260: U1.123 (PD7)
NET261: U1.77 (PD8)
NET262: U1.78 (PD9)
NET263: U1.79 (PD10)
NET264: U1.80 (PD11)
NET265: U1.81 (PD12)
NET266: U1.82 (PD13)
NET267: U1.85 (PD14)
NET268: U1.86 (PD15)
NET269: U1.141 (PE0)
NET270: U1.59 (PE8)
NET271: U1.60 (PE9)
NET272: U1.63 (PE10)
NET273: U1.64 (PE11)
NET274: U1.65 (PE12)
NET275: U1.66 (PE13)
NET276: U1.67 (PE14)
NET277: U1.68 (PE15)
NET278: U1.10 (PF0)
NET279: U1.11 (PF1)
NET280: U1.12 (PF2)
NET281: U1.13 (PF3)
NET282: U1.14 (PF4)
NET283: U1.15 (PF5)
NET284: U1.18 (PF6)
NET285: U1.19 (PF7)
NET286: U1.20 (PF8)
NET287: U1.21 (PF9)
NET288: U1.22 (PF10)
NET289: U1.49 (PF11)
NET290: U1.50 (PF12)
NET291: U1.53 (PF13)
NET292: U1.54 (PF14)
NET293: U1.55 (PF15)
NET294: U1.56 (PG0)
NET295: U1.57 (PG1)
NET296: U1.87 (PG2)
NET297: U1.88 (PG3)
NET298: U1.89 (PG4)
NET299: U1.90 (PG5)
NET300: U1.91 (PG6)
NET301: U1.92 (PG7)
NET302: U1.93 (PG8)
NET303: U1.124 (PG9)
NET304: U1.125 (PG10)
NET305: U1.127 (PG12)
NET306: U1.129 (PG14)
NET307: U1.132 (PG15)
NET314: U221.1 (NC1)
NET315: U221.2 (NC2)
NET316: U221.3 (NC3)
NET317: U221.7 (NC7)

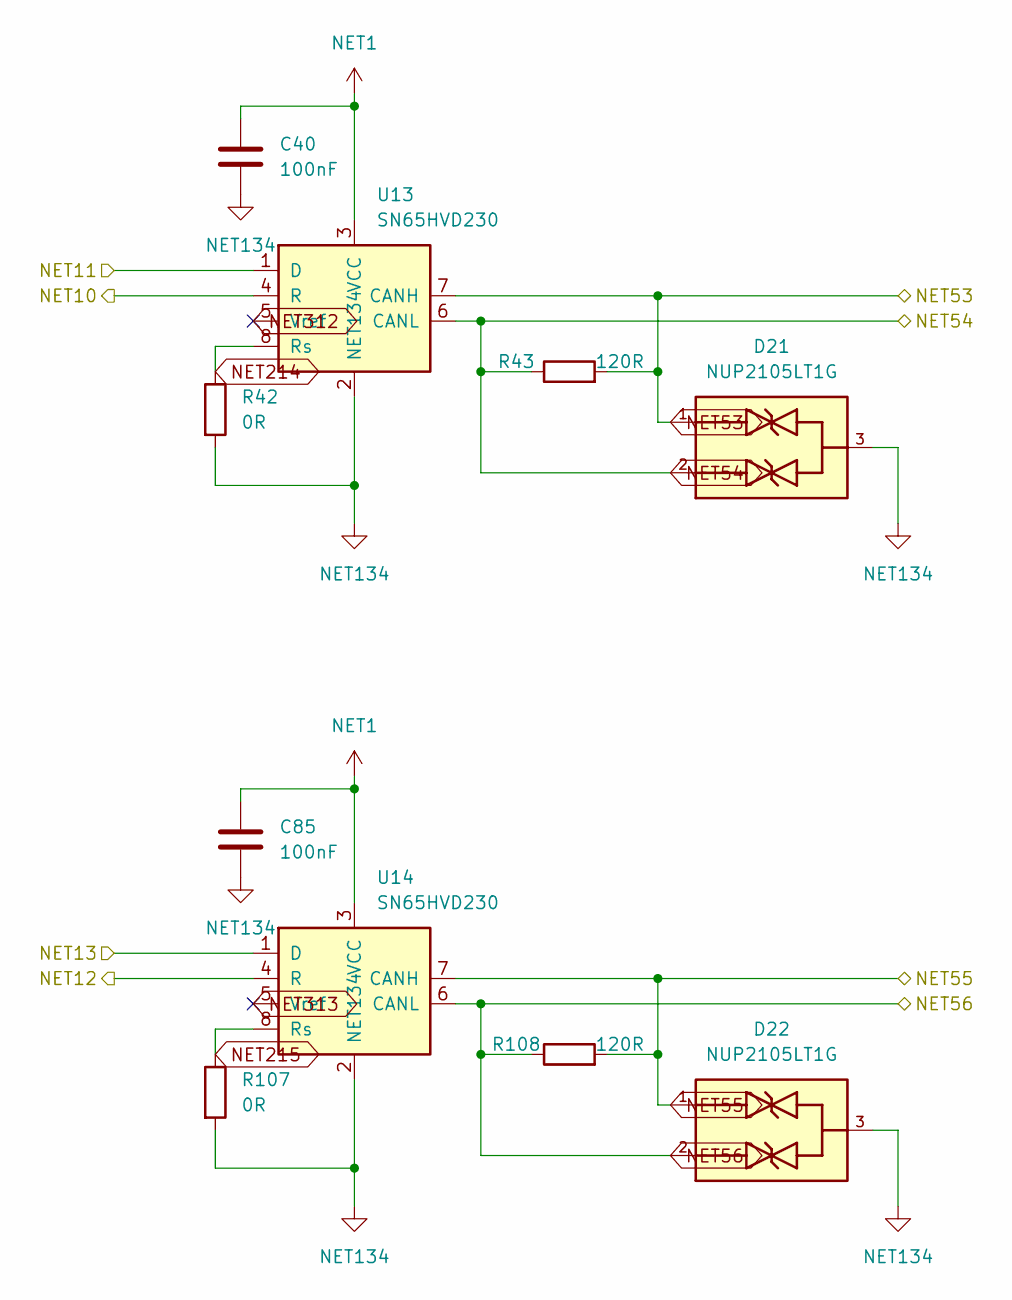
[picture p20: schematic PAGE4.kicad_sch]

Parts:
C40, C85: 100nF; C_0603_1608Metric
D21, D22: NUP2105LT1G; SOT95P237X111-3N; PARTREV 10
R42, R107: 0R; R_0603_1608Metric
R43, R108: 120R; R_0603_1608Metric
U13, U14: SN65HVD230; SOIC-8_3.9x4.9mm_P1.27mm

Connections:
NET1: C40.1, C85.1, U13.3 (VCC), U14.3 (VCC); also elsewhere on the board
NET10: U13.4 (R); also elsewhere on the board
NET11: U13.1 (D); also elsewhere on the board
NET12: U14.4 (R); also elsewhere on the board
NET13: U14.1 (D); also elsewhere on the board
NET53: D21.1, R43.2, U13.7 (CANH); also elsewhere on the board
NET54: D21.2, R43.1, U13.6 (CANL); also elsewhere on the board
NET55: D22.1, R108.2, U14.7 (CANH); also elsewhere on the board
NET56: D22.2, R108.1, U14.6 (CANL); also elsewhere on the board
NET134: C40.2, C85.2, D21.3, D22.3, R42.2, R107.2, U13.2 (GND), U14.2 (GND); also elsewhere on the board
NET214: R42.1, U13.8 (Rs)
NET215: R107.1, U14.8 (Rs)
NET312: U13.5 (Vref)
NET313: U14.5 (Vref)

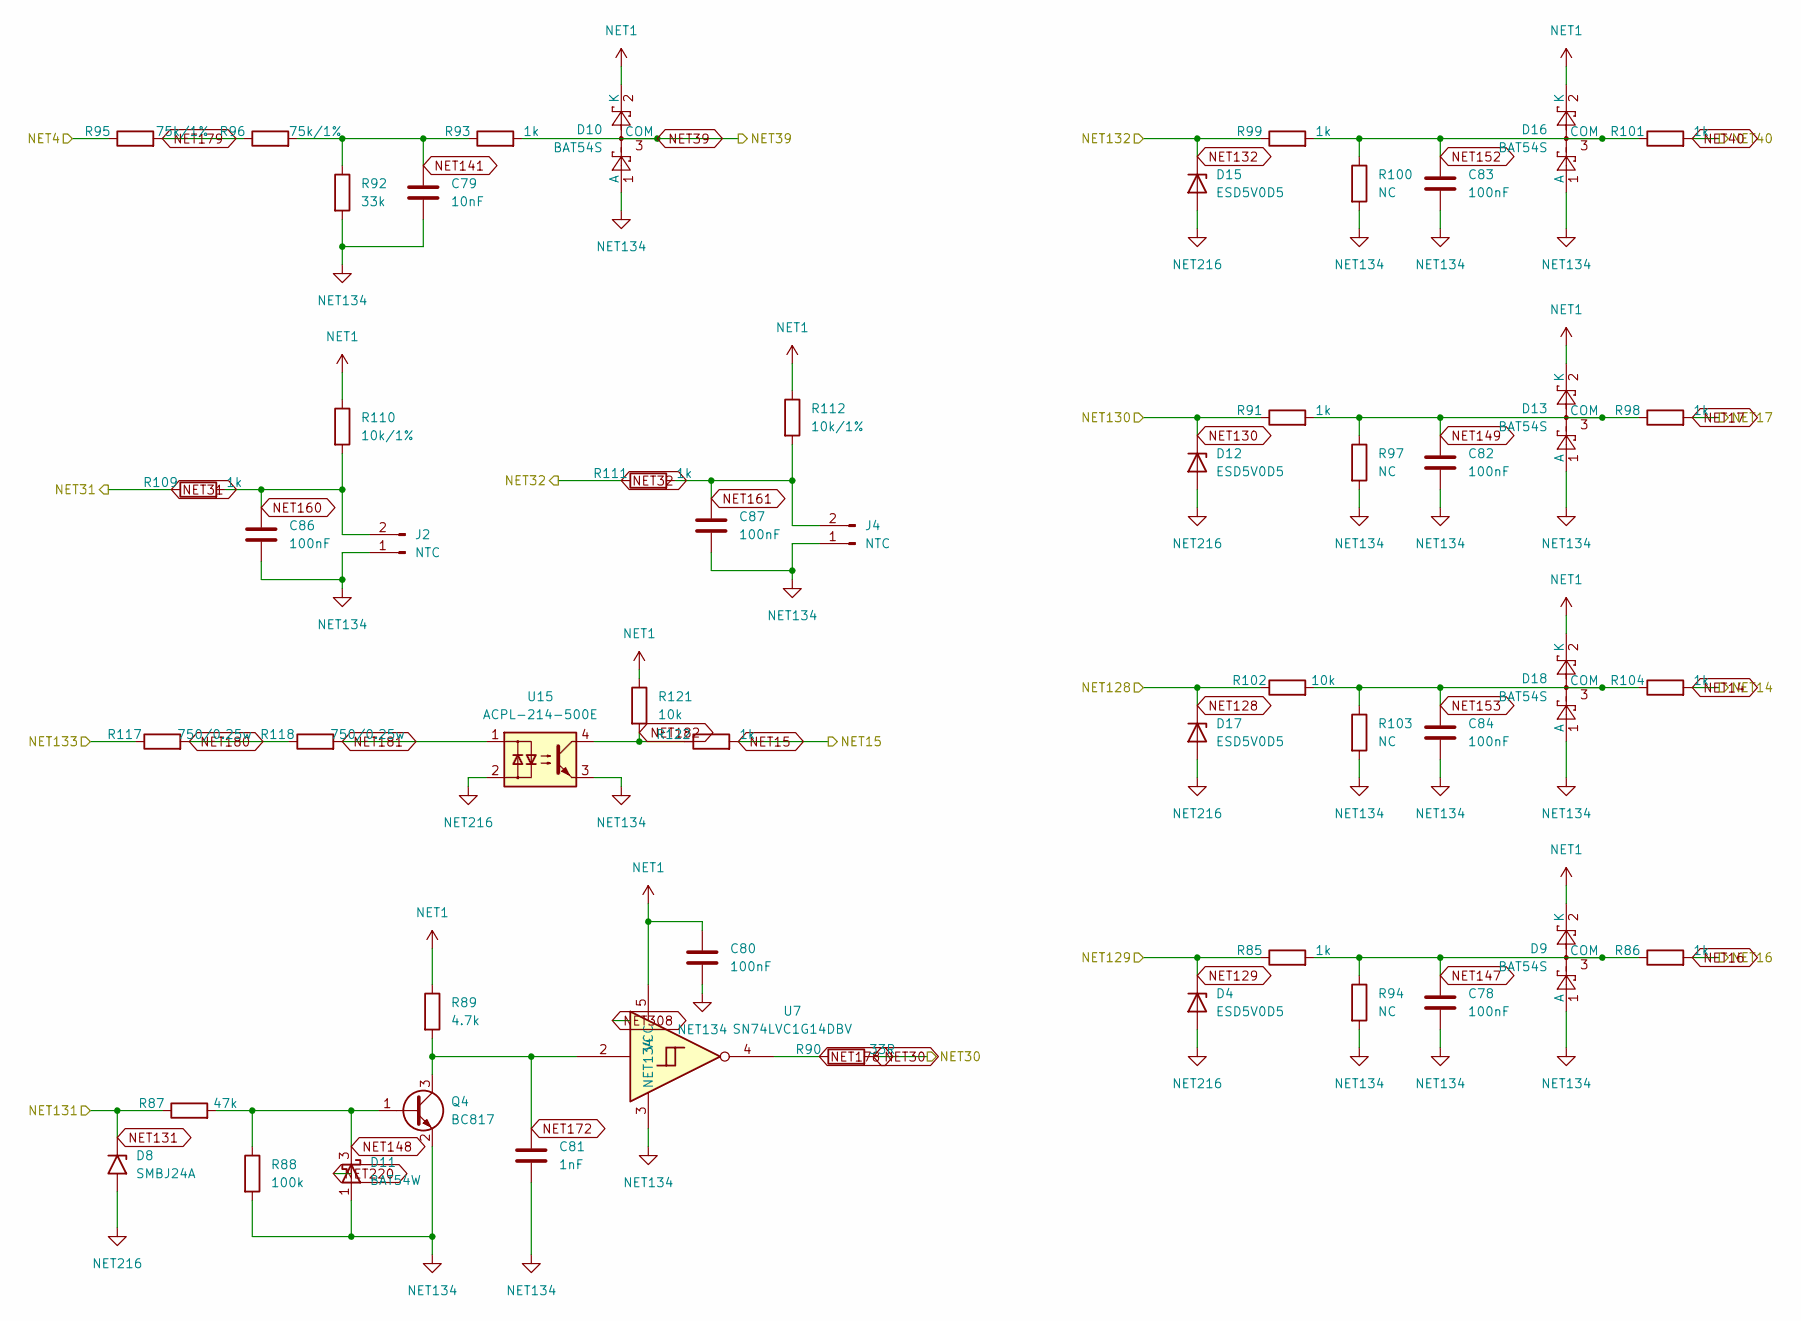
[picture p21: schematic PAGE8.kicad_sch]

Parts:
C78, C80, C82, C83, C84, C86, C87: 100nF; C_0603_1608Metric
C79: 10nF; C_0603_1608Metric
C81: 1nF; C_0603_1608Metric
D4, D12, D15, D17: ESD5V0D5; D_SOD-523
D8: SMBJ24A; D_SMB
D9, D10, D13, D16, D18: BAT54S; SOT-23
D11: BAT54W; SOT-323_SC-70
J2, J4: NTC; PinHeader_1x02_P2.54mm_Vertical
Q4: BC817; SOT-23
R85, R86, R91, R93, R98, R99, R101, R104, R109, R111, R122: 1k; R_0603_1608Metric
R87: 47k; R_0603_1608Metric
R88: 100k; R_0603_1608Metric
R89: 4.7k; R_0603_1608Metric
R90: 33R; R_0603_1608Metric
R92: 33k; R_0603_1608Metric
R94, R97, R100, R103: NC; R_0603_1608Metric
R95, R96: 75k/1%; R_0603_1608Metric
R102, R121: 10k; R_0603_1608Metric
R110, R112: 10k/1%; R_0603_1608Metric
R117, R118: 750/0.25w; R_1206_3216Metric
U7: SN74LVC1G14DBV; SOT-23-5
U15: ACPL-214-500E; SOP-4_4.4x2.6mm_P1.27mm

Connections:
NET1: C80.1, D9.2 (K), D10.2 (K), D13.2 (K), D16.2 (K), D18.2 (K), R89.1, R110.1, R112.1, R121.1, U7.5 (VCC); also elsewhere on the board
NET4: R95.1; also elsewhere on the board
NET14: R104.2; also elsewhere on the board
NET15: R122.2; also elsewhere on the board
NET16: R86.2; also elsewhere on the board
NET17: R98.2; also elsewhere on the board
NET30: R90.2; also elsewhere on the board
NET31: R109.1; also elsewhere on the board
NET32: R111.1; also elsewhere on the board
NET39: D10.3 (COM), R93.2; also elsewhere on the board
NET40: R101.2; also elsewhere on the board
NET128: D17.1 (K), R102.1; also elsewhere on the board
NET129: D4.1 (K), R85.1; also elsewhere on the board
NET130: D12.1 (K), R91.1; also elsewhere on the board
NET131: D8.1 (A1), R87.1; also elsewhere on the board
NET132: D15.1 (K), R99.1; also elsewhere on the board
NET133: R117.1; also elsewhere on the board
NET134: C78.2, C79.2, C80.2, C81.2, C82.2, C83.2, C84.2, C86.2, C87.2, D9.1 (A), D10.1 (A), D11.1 (A), D13.1 (A), D16.1 (A), D18.1 (A), J2.1, J4.1, Q4.2 (E), R88.2, R92.2, R94.2, R97.2, R100.2, R103.2, U7.3 (GND), U15.3; also elsewhere on the board
NET141: C79.1, R92.1, R93.1, R96.2
NET147: C78.1, D9.3 (COM), R85.2, R86.1, R94.1
NET148: D11.3 (K), Q4.1 (B), R87.2, R88.1
NET149: C82.1, D13.3 (COM), R91.2, R97.1, R98.1
NET152: C83.1, D16.3 (COM), R99.2, R100.1, R101.1
NET153: C84.1, D18.3 (COM), R102.2, R103.1, R104.1
NET160: C86.1, J2.2, R109.2, R110.2
NET161: C87.1, J4.2, R111.2, R112.2
NET172: C81.1, Q4.3 (C), R89.2, U7.2
NET178: R90.1, U7.4
NET179: R95.2, R96.1
NET180: R117.2, R118.1
NET181: R118.2, U15.1
NET182: R121.2, R122.1, U15.4
NET216: D4.2 (A), D8.2 (A2), D12.2 (A), D15.2 (A), D17.2 (A), U15.2; also elsewhere on the board
NET220: D11.2 (NC)
NET308: U7.1 (NC)

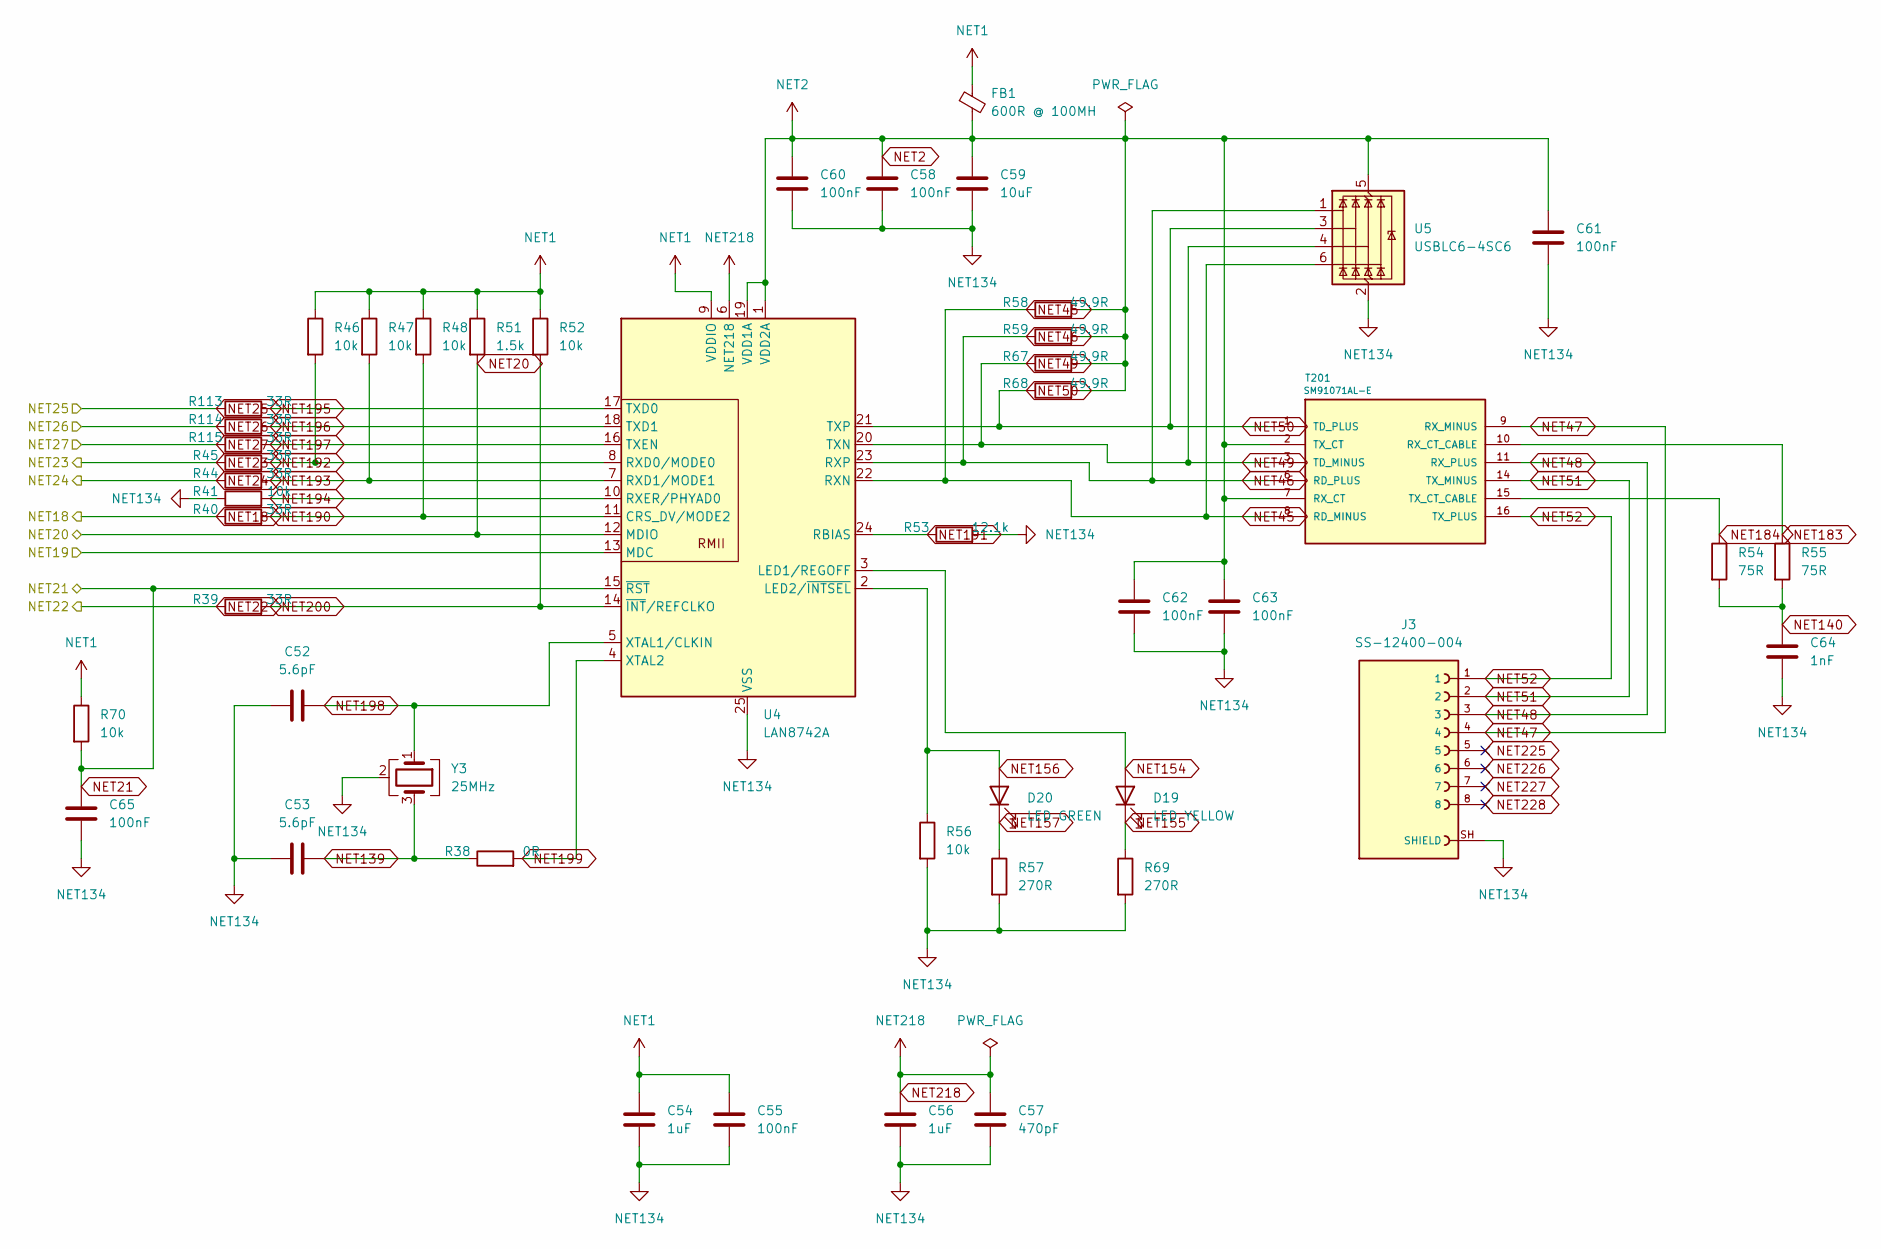
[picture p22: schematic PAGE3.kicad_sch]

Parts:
C52, C53: 5.6pF; C_0603_1608Metric
C54, C56: 1uF; C_0603_1608Metric
C55, C58, C60, C61, C62, C63, C65: 100nF; C_0603_1608Metric
C57: 470pF; C_0603_1608Metric
C59: 10uF; C_0603_1608Metric
C64: 1nF; C_0603_1608Metric
D19: LED YELLOW; LED_0603_1608Metric
D20: LED GREEN; LED_0603_1608Metric
FB1: 600R @ 100MH; L_0805_2012Metric
J3: SS-12400-004; CINCH_SS-12400-004; PARTREV A0
R38: 0R; R_0603_1608Metric
R39, R40, R44, R45, R113, R114, R115: 33R; R_0603_1608Metric
R41, R46, R47, R48, R52, R56, R70: 10k; R_0603_1608Metric
R51: 1.5k; R_0603_1608Metric
R53: 12.1k; R_0603_1608Metric
R54, R55: 75R; R_0603_1608Metric
R57, R69: 270R; R_0603_1608Metric
R58, R59, R67, R68: 49.9R; R_0603_1608Metric
T201: SM91071AL-E; Bourns_SM91071AL-E
U4: LAN8742A; VQFN-24-1EP_4x4mm_P0.5mm_EP2.5x2.5mm_POFV
U5: USBLC6-4SC6; SOT-23-6
Y3: 25MHz; Crystal_SMD_3225-4Pin_3.2x2.5mm

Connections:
NET1: C54.1, C55.1, FB1.1, R46.1, R47.1, R48.1, R51.1, R52.1, R70.1, U4.9 (VDDIO); also elsewhere on the board
NET2: C58.1, C59.1, C60.1, C61.1, C62.1, C63.1, FB1.2, R58.2, R59.2, R67.2, R68.2, T201.2 (TX_CT), T201.7 (RX_CT), U4.1 (VDD2A), U4.19 (VDD1A), U5.5 (VBUS)
NET18: R40.1; also elsewhere on the board
NET19: U4.13 (MDC); also elsewhere on the board
NET20: R51.2, U4.12 (MDIO); also elsewhere on the board
NET21: C65.1, R70.2, U4.15 (~RST); also elsewhere on the board
NET22: R39.1; also elsewhere on the board
NET23: R45.1; also elsewhere on the board
NET24: R44.1; also elsewhere on the board
NET25: R113.1; also elsewhere on the board
NET26: R114.1; also elsewhere on the board
NET27: R115.1; also elsewhere on the board
NET45: R58.1, T201.8 (RD_MINUS), U4.22 (RXN), U5.6 (I/O4)
NET46: R59.1, T201.6 (RD_PLUS), U4.23 (RXP), U5.1 (I/O1)
NET47: J3.4, T201.9 (RX_MINUS)
NET48: J3.3, T201.11 (RX_PLUS)
NET49: R67.1, T201.3 (TD_MINUS), U4.20 (TXN), U5.4 (I/O3)
NET50: R68.1, T201.1 (TD_PLUS), U4.21 (TXP), U5.3 (I/O2)
NET51: J3.2, T201.14 (TX_MINUS)
NET52: J3.1, T201.16 (TX_PLUS)
NET134: C52.1, C53.1, C54.2, C55.2, C56.2, C57.2, C58.2, C59.2, C60.2, C61.2, C62.2, C63.2, C64.2, C65.2, J3.SH (SHIELD), R41.1, R53.2, R56.2, R57.2, R69.2, U4.25 (VSS), U5.2 (GND), Y3.2 (G), Y3.4 (G); also elsewhere on the board
NET139: C53.2, R38.1, Y3.3
NET140: C64.1, R54.2, R55.2
NET154: D19.2 (A), U4.3 (LED1/REGOFF)
NET155: D19.1 (K), R69.1
NET156: D20.2 (A), R56.1, U4.2 (LED2/~INTSEL)
NET157: D20.1 (K), R57.1
NET183: R55.1, T201.10 (RX_CT_CABLE)
NET184: R54.1, T201.15 (TX_CT_CABLE)
NET190: R40.2, R48.2, U4.11 (CRS_DV/MODE2)
NET191: R53.1, U4.24 (RBIAS)
NET192: R45.2, R46.2, U4.8 (RXD0/MODE0)
NET193: R44.2, R47.2, U4.7 (RXD1/MODE1)
NET194: R41.2, U4.10 (RXER/PHYAD0)
NET195: R113.2, U4.17 (TXD0)
NET196: R114.2, U4.18 (TXD1)
NET197: R115.2, U4.16 (TXEN)
NET198: C52.2, U4.5 (XTAL1/CLKIN), Y3.1
NET199: R38.2, U4.4 (XTAL2)
NET200: R39.2, R52.2, U4.14 (~INT/REFCLKO)
NET218: C56.1, C57.1, U4.6 (VDDCR)
NET225: J3.5
NET226: J3.6
NET227: J3.7
NET228: J3.8

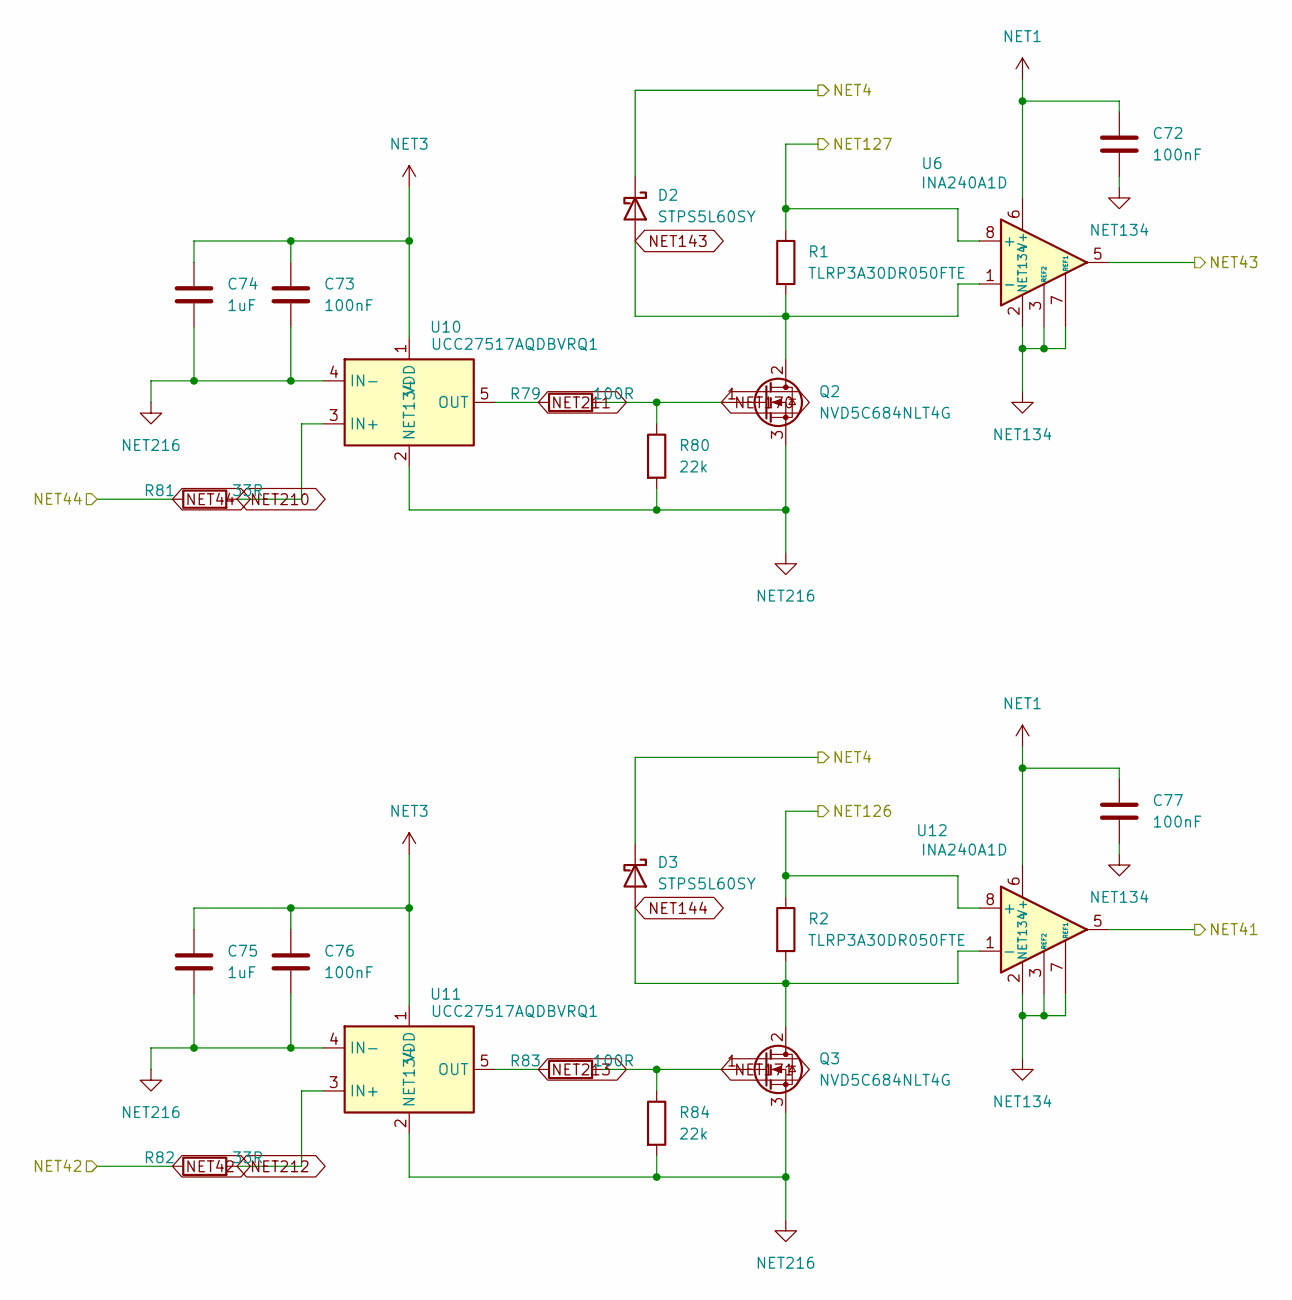
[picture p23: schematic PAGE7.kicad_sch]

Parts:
C72, C73, C76, C77: 100nF; C_0603_1608Metric
C74, C75: 1uF; C_0603_1608Metric
D2, D3: STPS5L60SY; D_SMC
Q2, Q3: NVD5C684NLT4G; TO-252-2
R1, R2: TLRP3A30DR050FTE; R_2512_6332Metric
R79, R83: 100R; R_0603_1608Metric
R80, R84: 22k; R_0603_1608Metric
R81, R82: 33R; R_0603_1608Metric
U6, U12: INA240A1D; SOIC-8_3.9x4.9mm_P1.27mm
U10, U11: UCC27517AQDBVRQ1; SOT-23-5_TI_DBV

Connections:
NET1: C72.1, C77.1, U6.6 (V+), U12.6 (V+); also elsewhere on the board
NET3: C73.1, C74.1, C75.1, C76.1, U10.1 (VDD), U11.1 (VDD); also elsewhere on the board
NET4: D2.1 (K), D3.1 (K); also elsewhere on the board
NET41: U12.5; also elsewhere on the board
NET42: R82.1; also elsewhere on the board
NET43: U6.5; also elsewhere on the board
NET44: R81.1; also elsewhere on the board
NET126: R2.1, U12.8 (+); also elsewhere on the board
NET127: R1.1, U6.8 (+); also elsewhere on the board
NET134: C72.2, C77.2, U6.2 (GND), U6.3 (REF2), U6.4 (GND), U6.7 (REF1), U12.2 (GND), U12.3 (REF2), U12.4 (GND), U12.7 (REF1); also elsewhere on the board
NET143: D2.2 (A), Q2.2 (D), R1.2, U6.1 (-)
NET144: D3.2 (A), Q3.2 (D), R2.2, U12.1 (-)
NET170: Q2.1 (G), R79.2, R80.1
NET171: Q3.1 (G), R83.2, R84.1
NET210: R81.2, U10.3 (IN+)
NET211: R79.1, U10.5 (OUT)
NET212: R82.2, U11.3 (IN+)
NET213: R83.1, U11.5 (OUT)
NET216: C73.2, C74.2, C75.2, C76.2, Q2.3 (S), Q3.3 (S), R80.2, R84.2, U10.2 (GND), U10.4 (IN-), U11.2 (GND), U11.4 (IN-); also elsewhere on the board

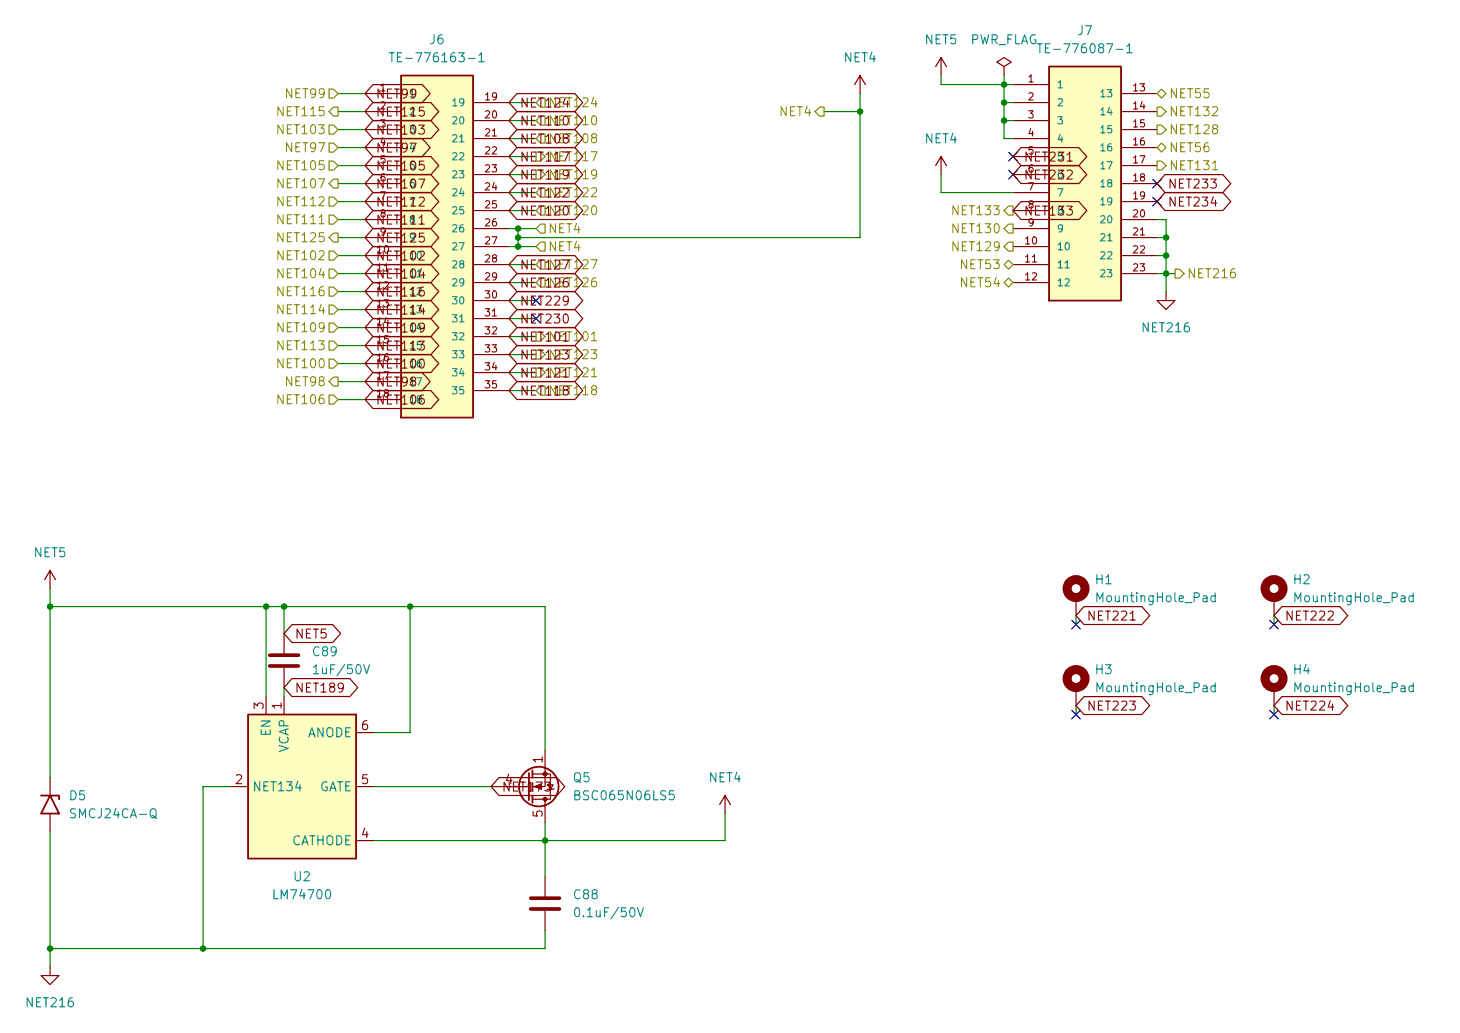
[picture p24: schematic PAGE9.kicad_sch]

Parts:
C88: 0.1uF/50V; C_0603_1608Metric
C89: 1uF/50V; C_0603_1608Metric
D5: SMCJ24CA-Q; D_SMC
H1, H2, H3, H4: MountingHole_Pad; MountingHole_3.2mm_M3_ISO7380_Pad
J6: TE-776163-1; TE_776163-1
J7: TE-776087-1; TE_776087-1; PARTREV E11
Q5: BSC065N06LS5; TDSON-8-1
U2: LM74700; SOT-23-6

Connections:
NET4: C88.1, J6.26, J6.27, J7.7, Q5.5 (D), U2.4 (CATHODE); also elsewhere on the board
NET5: C89.1, D5.1 (A1), J7.1, J7.2, J7.3, J7.4, Q5.1 (S), Q5.2 (S), Q5.3 (S), U2.3 (EN), U2.6 (ANODE); also elsewhere on the board
NET53: J7.11; also elsewhere on the board
NET54: J7.12; also elsewhere on the board
NET55: J7.13; also elsewhere on the board
NET56: J7.16; also elsewhere on the board
NET97: J6.4; also elsewhere on the board
NET98: J6.17; also elsewhere on the board
NET99: J6.1; also elsewhere on the board
NET100: J6.16; also elsewhere on the board
NET101: J6.32; also elsewhere on the board
NET102: J6.10; also elsewhere on the board
NET103: J6.3; also elsewhere on the board
NET104: J6.11; also elsewhere on the board
NET105: J6.5; also elsewhere on the board
NET106: J6.18; also elsewhere on the board
NET107: J6.6; also elsewhere on the board
NET108: J6.21; also elsewhere on the board
NET109: J6.14; also elsewhere on the board
NET110: J6.20; also elsewhere on the board
NET111: J6.8; also elsewhere on the board
NET112: J6.7; also elsewhere on the board
NET113: J6.15; also elsewhere on the board
NET114: J6.13; also elsewhere on the board
NET115: J6.2; also elsewhere on the board
NET116: J6.12; also elsewhere on the board
NET117: J6.22; also elsewhere on the board
NET118: J6.35; also elsewhere on the board
NET119: J6.23; also elsewhere on the board
NET120: J6.25; also elsewhere on the board
NET121: J6.34; also elsewhere on the board
NET122: J6.24; also elsewhere on the board
NET123: J6.33; also elsewhere on the board
NET124: J6.19; also elsewhere on the board
NET125: J6.9; also elsewhere on the board
NET126: J6.29; also elsewhere on the board
NET127: J6.28; also elsewhere on the board
NET128: J7.15; also elsewhere on the board
NET129: J7.10; also elsewhere on the board
NET130: J7.9; also elsewhere on the board
NET131: J7.17; also elsewhere on the board
NET132: J7.14; also elsewhere on the board
NET133: J7.8; also elsewhere on the board
NET173: Q5.4 (G), U2.5 (GATE)
NET189: C89.2, U2.1 (VCAP)
NET216: C88.2, D5.2 (A2), J7.20, J7.21, J7.22, J7.23, U2.2 (GND); also elsewhere on the board
NET221: H1.1 (1_1)
NET222: H2.1 (1_1)
NET223: H3.1 (1_1)
NET224: H4.1 (1_1)
NET229: J6.30
NET230: J6.31
NET231: J7.5
NET232: J7.6
NET233: J7.18
NET234: J7.19

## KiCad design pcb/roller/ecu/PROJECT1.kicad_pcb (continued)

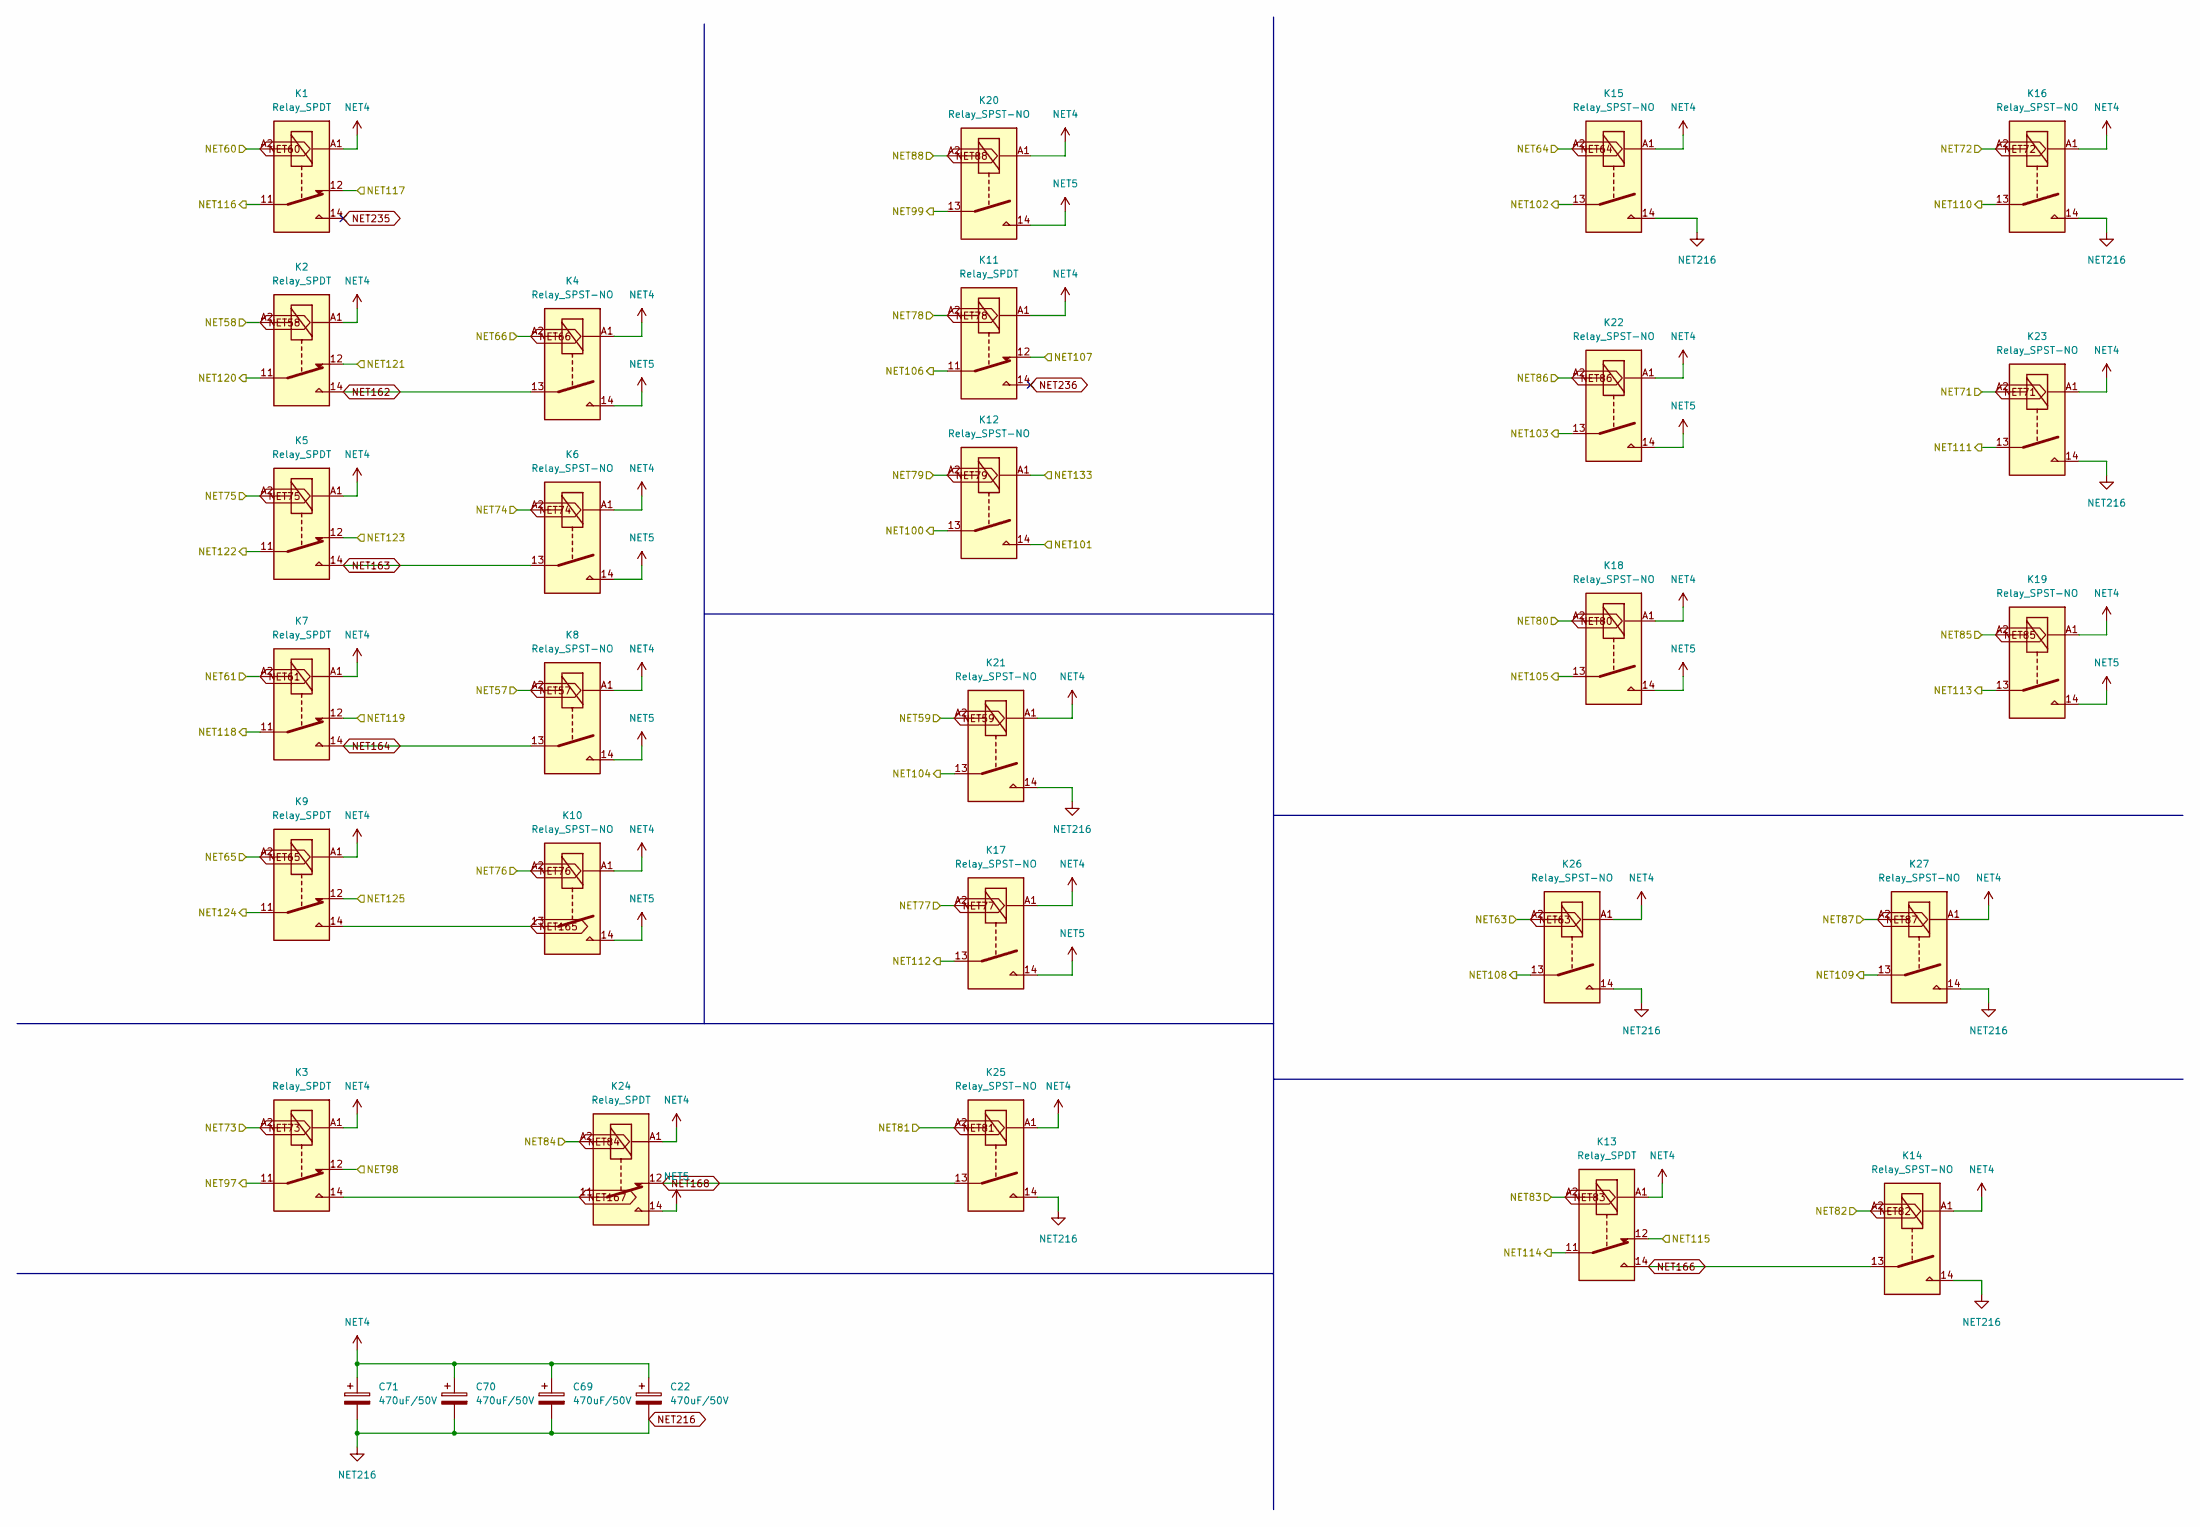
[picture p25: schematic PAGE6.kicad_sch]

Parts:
C22, C69, C70, C71: 470uF/50V; CP_Elec_5x5.4
K1, K2, K3, K5, K7, K9, K11, K13, K24: Relay_SPDT; Relay_SPDT_Hongfa_HFV6_1FormC
K4, K6, K8, K10, K12, K14, K15, K16, K17, K18, K19, K20, K21, K22, K23, K25, K26, K27: Relay_SPST-NO; Relay_SPST-NO_Hongfa_HFV6_1FormA

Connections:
NET4: C22.1, C69.1, C70.1, C71.1, K1.A1, K2.A1, K3.A1, K4.A1, K5.A1, K6.A1, K7.A1, K8.A1, K9.A1, K10.A1, K11.A1, K13.A1, K14.A1, K15.A1, K16.A1, K17.A1, K18.A1, K19.A1, K20.A1, K21.A1, K22.A1, K23.A1, K24.A1, K25.A1, K26.A1, K27.A1; also elsewhere on the board
NET5: K4.14, K6.14, K8.14, K10.14, K17.14, K18.14, K19.14, K20.14, K22.14, K24.14; also elsewhere on the board
NET57: K8.A2; also elsewhere on the board
NET58: K2.A2; also elsewhere on the board
NET59: K21.A2; also elsewhere on the board
NET60: K1.A2; also elsewhere on the board
NET61: K7.A2; also elsewhere on the board
NET63: K26.A2; also elsewhere on the board
NET64: K15.A2; also elsewhere on the board
NET65: K9.A2; also elsewhere on the board
NET66: K4.A2; also elsewhere on the board
NET71: K23.A2; also elsewhere on the board
NET72: K16.A2; also elsewhere on the board
NET73: K3.A2; also elsewhere on the board
NET74: K6.A2; also elsewhere on the board
NET75: K5.A2; also elsewhere on the board
NET76: K10.A2; also elsewhere on the board
NET77: K17.A2; also elsewhere on the board
NET78: K11.A2; also elsewhere on the board
NET79: K12.A2; also elsewhere on the board
NET80: K18.A2; also elsewhere on the board
NET81: K25.A2; also elsewhere on the board
NET82: K14.A2; also elsewhere on the board
NET83: K13.A2; also elsewhere on the board
NET84: K24.A2; also elsewhere on the board
NET85: K19.A2; also elsewhere on the board
NET86: K22.A2; also elsewhere on the board
NET87: K27.A2; also elsewhere on the board
NET88: K20.A2; also elsewhere on the board
NET97: K3.11; also elsewhere on the board
NET98: K3.12; also elsewhere on the board
NET99: K20.13; also elsewhere on the board
NET100: K12.13; also elsewhere on the board
NET101: K12.14; also elsewhere on the board
NET102: K15.13; also elsewhere on the board
NET103: K22.13; also elsewhere on the board
NET104: K21.13; also elsewhere on the board
NET105: K18.13; also elsewhere on the board
NET106: K11.11; also elsewhere on the board
NET107: K11.12; also elsewhere on the board
NET108: K26.13; also elsewhere on the board
NET109: K27.13; also elsewhere on the board
NET110: K16.13; also elsewhere on the board
NET111: K23.13; also elsewhere on the board
NET112: K17.13; also elsewhere on the board
NET113: K19.13; also elsewhere on the board
NET114: K13.11; also elsewhere on the board
NET115: K13.12; also elsewhere on the board
NET116: K1.11; also elsewhere on the board
NET117: K1.12; also elsewhere on the board
NET118: K7.11; also elsewhere on the board
NET119: K7.12; also elsewhere on the board
NET120: K2.11; also elsewhere on the board
NET121: K2.12; also elsewhere on the board
NET122: K5.11; also elsewhere on the board
NET123: K5.12; also elsewhere on the board
NET124: K9.11; also elsewhere on the board
NET125: K9.12; also elsewhere on the board
NET133: K12.A1; also elsewhere on the board
NET162: K2.14, K4.13
NET163: K5.14, K6.13
NET164: K7.14, K8.13
NET165: K9.14, K10.13
NET166: K13.14, K14.13
NET167: K3.14, K24.11
NET168: K24.12, K25.13
NET216: C22.2, C69.2, C70.2, C71.2, K14.14, K15.14, K16.14, K21.14, K23.14, K25.14, K26.14, K27.14; also elsewhere on the board
NET235: K1.14
NET236: K11.14

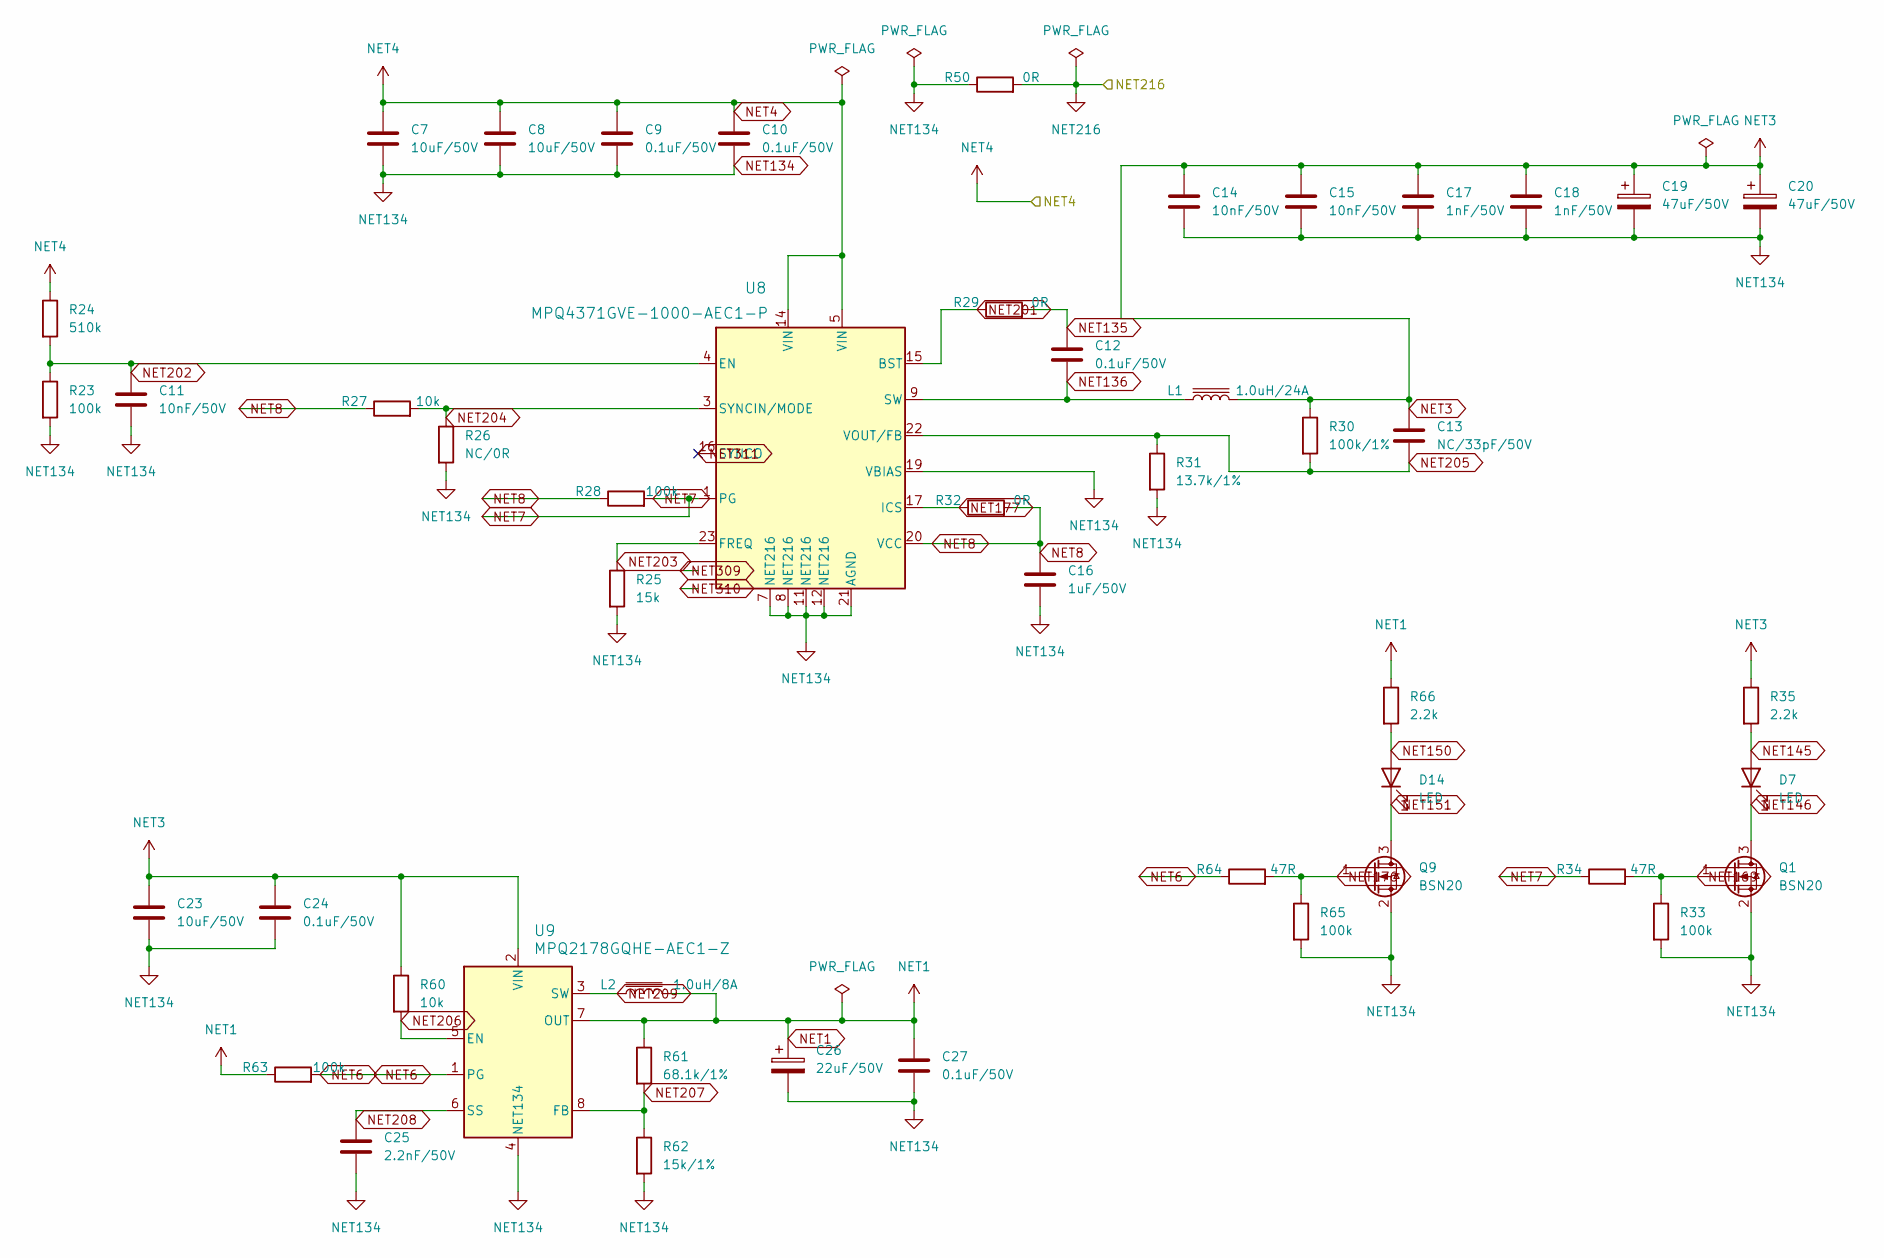
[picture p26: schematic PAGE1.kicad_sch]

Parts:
C7, C8, C23: 10uF/50V; C_0603_1608Metric
C9, C10, C12, C24, C27: 0.1uF/50V; C_0603_1608Metric
C11, C14, C15: 10nF/50V; C_0603_1608Metric
C13: NC/33pF/50V; C_0603_1608Metric
C16: 1uF/50V; C_0603_1608Metric
C17, C18: 1nF/50V; C_0603_1608Metric
C19, C20: 47uF/50V; CP_Elec_5x5.4
C25: 2.2nF/50V; C_0603_1608Metric
C26: 22uF/50V; CP_Elec_5x5.4
D7, D14: LED; LED_0603_1608Metric
L1: 1.0uH/24A; L_APV_APH1040
L2: 1.0uH/8A; L_APV_APH0630
Q1, Q9: BSN20; SOT-23
R23, R28, R33, R63, R65: 100k; R_0603_1608Metric
R24: 510k; R_0603_1608Metric
R25: 15k; R_0603_1608Metric
R26: NC/0R; R_0603_1608Metric
R27, R60: 10k; R_0603_1608Metric
R29, R32, R50: 0R; R_0603_1608Metric
R30: 100k/1%; R_0603_1608Metric
R31: 13.7k/1%; R_0603_1608Metric
R34, R64: 47R; R_0603_1608Metric
R35, R66: 2.2k; R_0603_1608Metric
R61: 68.1k/1%; R_0603_1608Metric
R62: 15k/1%; R_0603_1608Metric
U8: MPQ4371GVE-1000-AEC1-P; QFN-234MMX5MM_MPQ4371_MNP
U9: MPQ2178GQHE-AEC1-Z; QFN-8_MPQ2178GQHE

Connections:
NET1: C26.1, C27.1, L2.2, R61.1, R63.1, R66.1, U9.7 (OUT); also elsewhere on the board
NET3: C13.1, C14.1, C15.1, C17.1, C18.1, C19.1, C20.1, C23.1, C24.1, L1.2, R30.1, R35.1, R60.1, U9.2 (VIN); also elsewhere on the board
NET4: C7.1, C8.1, C9.1, C10.1, R24.1, U8.5 (VIN), U8.14 (VIN); also elsewhere on the board
NET6: R63.2, R64.1, U9.1 (PG)
NET7: R28.2, R34.1, U8.1 (PG), U8.2 (PG)
NET8: C16.1, R27.1, R28.1, R32.2, U8.20 (VCC)
NET134: C7.2, C8.2, C9.2, C10.2, C11.2, C14.2, C15.2, C16.2, C17.2, C18.2, C19.2, C20.2, C23.2, C24.2, C25.2, C26.2, C27.2, Q1.2 (S), Q9.2 (S), R23.2, R25.2, R26.2, R31.2, R33.2, R50.1, R62.2, R65.2, U8.7 (PGND), U8.8 (PGND), U8.11 (PGND), U8.12 (PGND), U8.19 (VBIAS), U8.21 (AGND), U9.4 (GND); also elsewhere on the board
NET135: C12.1, R29.2
NET136: C12.2, L1.1, U8.9 (SW), U8.10 (SW)
NET145: D7.2 (A), R35.2
NET146: D7.1 (K), Q1.3 (D)
NET150: D14.2 (A), R66.2
NET151: D14.1 (K), Q9.3 (D)
NET169: Q1.1 (G), R33.1, R34.2
NET176: Q9.1 (G), R64.2, R65.1
NET177: R32.1, U8.17 (ICS), U8.18 (ICS)
NET201: R29.1, U8.15 (BST)
NET202: C11.1, R23.1, R24.2, U8.4 (EN)
NET203: R25.1, U8.23 (FREQ)
NET204: R26.1, R27.2, U8.3 (SYNCIN/MODE)
NET205: C13.2, R30.2, R31.1, U8.22 (VOUT/FB)
NET206: R60.2, U9.5 (EN)
NET207: R61.2, R62.1, U9.8 (FB)
NET208: C25.1, U9.6 (SS)
NET209: L2.1, U9.3 (SW)
NET216: R50.2; also elsewhere on the board
NET309: U8.6 (NC)
NET310: U8.13 (NC)
NET311: U8.16 (SYNCO)

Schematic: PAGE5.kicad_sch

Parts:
C5, C21, C66, C67, C68: 100nF; C_0603_1608Metric
Q6: 2N7002KQ-7; SOT-23
R71: 1.5k; R_0603_1608Metric
R72, R73, R74, R75, R76: 10k; R_0603_1608Metric
R77: 330R; R_0603_1608Metric
R78: 100k; R_0603_1608Metric
U300: SN74AHCT541QPWRQ1; TSSOP-20_4.4x6.5mm_P0.65mm
U301, U302, U303, U304: TPIC6A595DWR; SOIC-24W_7.5x15.4mm_P1.27mm

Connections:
NET3: C5.1, C21.1, C66.1, C67.1, C68.1, R71.1, R72.1, U300.20 (VCC), U301.21 (VCC), U302.21 (VCC), U303.21 (VCC), U304.21 (VCC); also elsewhere on the board
NET33: U300.5 (A3); also elsewhere on the board
NET34: R77.1; also elsewhere on the board
NET35: U300.6 (A4); also elsewhere on the board
NET36: U300.4 (A2); also elsewhere on the board
NET37: U300.2 (A0); also elsewhere on the board
NET38: U300.3 (A1); also elsewhere on the board
NET57: U301.23 (DRAIN0); also elsewhere on the board
NET58: U301.24 (DRAIN1); also elsewhere on the board
NET59: U301.1 (DRAIN2); also elsewhere on the board
NET60: U301.2 (DRAIN3); also elsewhere on the board
NET61: U301.11 (DRAIN4); also elsewhere on the board
NET62: U301.12 (DRAIN5)
NET63: U301.13 (DRAIN6); also elsewhere on the board
NET64: U301.14 (DRAIN7); also elsewhere on the board
NET65: U302.23 (DRAIN0); also elsewhere on the board
NET66: U302.24 (DRAIN1); also elsewhere on the board
NET67: U302.1 (DRAIN2)
NET68: U302.2 (DRAIN3)
NET69: U302.11 (DRAIN4)
NET70: U302.12 (DRAIN5)
NET71: U302.13 (DRAIN6); also elsewhere on the board
NET72: U302.14 (DRAIN7); also elsewhere on the board
NET73: U303.23 (DRAIN0); also elsewhere on the board
NET74: U303.24 (DRAIN1); also elsewhere on the board
NET75: U303.1 (DRAIN2); also elsewhere on the board
NET76: U303.2 (DRAIN3); also elsewhere on the board
NET77: U303.11 (DRAIN4); also elsewhere on the board
NET78: U303.12 (DRAIN5); also elsewhere on the board
NET79: U303.13 (DRAIN6); also elsewhere on the board
NET80: U303.14 (DRAIN7); also elsewhere on the board
NET81: U304.23 (DRAIN0); also elsewhere on the board
NET82: U304.24 (DRAIN1); also elsewhere on the board
NET83: U304.1 (DRAIN2); also elsewhere on the board
NET84: U304.2 (DRAIN3); also elsewhere on the board
NET85: U304.11 (DRAIN4); also elsewhere on the board
NET86: U304.12 (DRAIN5); also elsewhere on the board
NET87: U304.13 (DRAIN6); also elsewhere on the board
NET88: U304.14 (DRAIN7); also elsewhere on the board
NET89: R73.1, U300.15 (Y3), U301.3 (SRCLR_N), U302.3 (SRCLR_N), U303.3 (SRCLR_N), U304.3 (SRCLR_N)
NET90: R72.2, U300.14 (Y4), U301.4 (G_N), U302.4 (G_N), U303.4 (G_N), U304.4 (G_N)
NET91: R74.1, U300.16 (Y2), U301.9 (RCK), U302.9 (RCK), U303.9 (RCK), U304.9 (RCK)
NET92: R76.1, U300.18 (Y0), U301.22 (SERIN)
NET93: R75.1, U300.17 (Y1), U301.10 (SRCK), U302.10 (SRCK), U303.10 (SRCK), U304.10 (SRCK)
NET94: U301.15 (SEROUT), U302.22 (SERIN)
NET95: U302.15 (SEROUT), U303.22 (SERIN)
NET96: U303.15 (SEROUT), U304.22 (SERIN)
NET134: C5.2, C21.2, C66.2, C67.2, C68.2, Q6.2 (S), R73.2, R74.2, R75.2, R76.2, R78.2, U300.7 (A5), U300.8 (A6), U300.9 (A7), U300.10 (GND), U301.16 (LGND), U302.16 (LGND), U303.16 (LGND), U304.16 (LGND); also elsewhere on the board
NET174: Q6.3 (D), R71.2, U300.1 (G1), U300.19 (G2)
NET175: Q6.1 (G), R77.2, R78.1
NET216: U301.5 (PGND1), U301.6 (PGND2), U301.7 (PGND3), U301.8 (PGND4), U301.17 (PGND5), U301.18 (PGND6), U301.19 (PGND7), U301.20 (PGND8), U302.5 (PGND1), U302.6 (PGND2), U302.7 (PGND3), U302.8 (PGND4), U302.17 (PGND5), U302.18 (PGND6), U302.19 (PGND7), U302.20 (PGND8), U303.5 (PGND1), U303.6 (PGND2), U303.7 (PGND3), U303.8 (PGND4), U303.17 (PGND5), U303.18 (PGND6), U303.19 (PGND7), U303.20 (PGND8), U304.5 (PGND1), U304.6 (PGND2), U304.7 (PGND3), U304.8 (PGND4), U304.17 (PGND5), U304.18 (PGND6), U304.19 (PGND7), U304.20 (PGND8); also elsewhere on the board
NET318: U300.13 (Y5)
NET319: U300.12 (Y6)
NET320: U300.11 (Y7)
NET321: U304.15 (SEROUT)

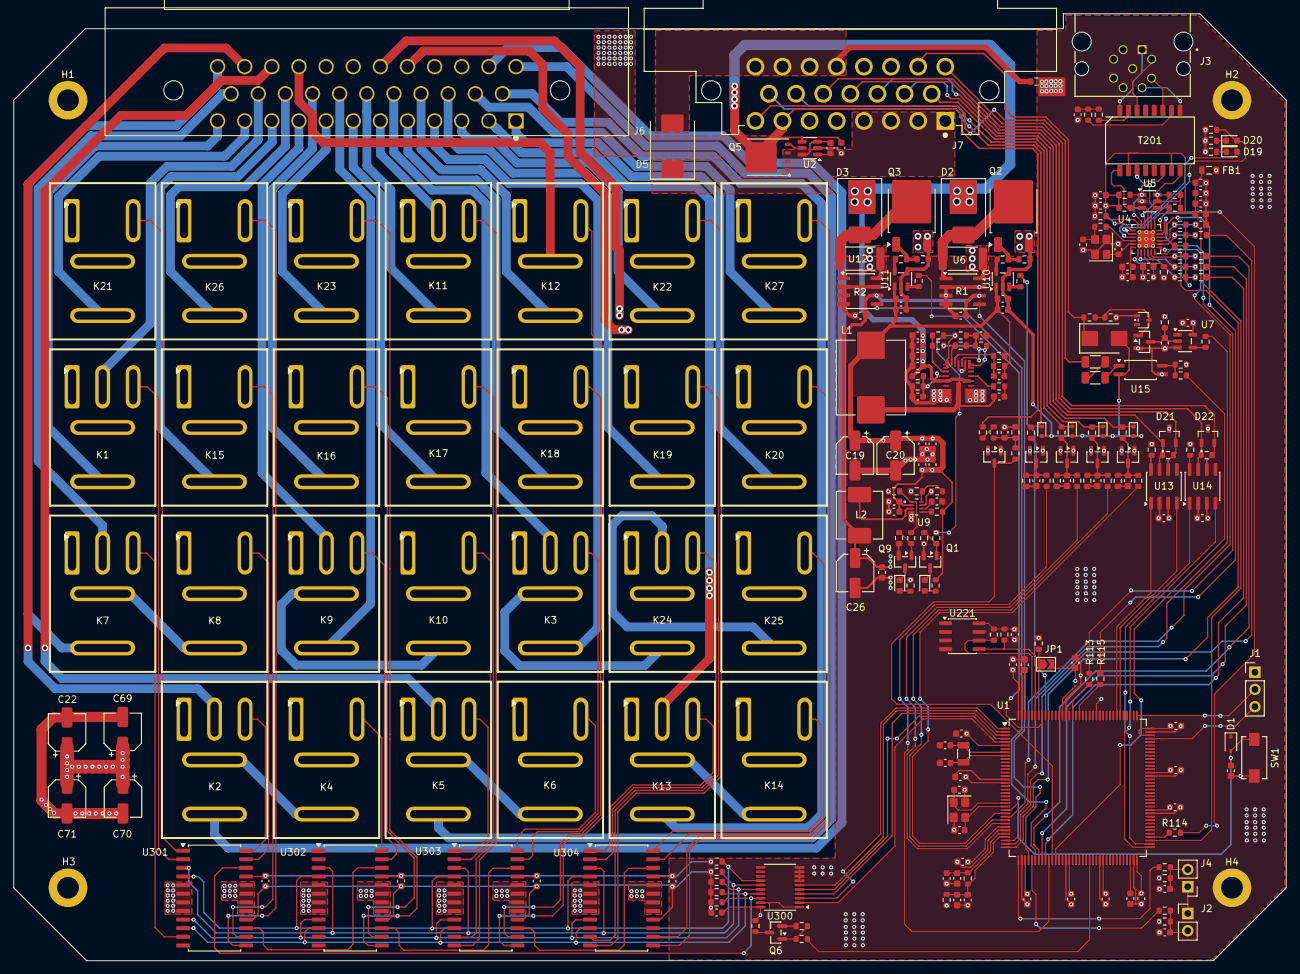
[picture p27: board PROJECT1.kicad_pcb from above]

Board: 4 copper layers, 187.6 x 139.6 mm, 278 parts (0 on the bottom side), 214 nets.

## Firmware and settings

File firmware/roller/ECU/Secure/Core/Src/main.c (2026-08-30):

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
/* Includes ------------------------------------------------------------------*/
#include "main.h"
#include "adc.h"
#include "fdcan.h"
#include "gpdma.h"
#include "gtzc_s.h"
#include "icache.h"
#include "iwdg.h"
#include "spi.h"
#include "tim.h"
#include "gpio.h"

/* USER CODE BEGIN Includes */
#include <stdbool.h>

#include "safety_service.h"
#include "secure_timebase.h"

/* USER CODE END Includes */

/* USER CODE BEGIN VTOR_TABLE */

/* Non-secure Vector table to jump to (internal Flash Bank2 here)             */
/* Caution: address must correspond to non-secure internal Flash where is     */
/*          mapped in the non-secure vector table                             */
#if defined(ECU_OEMIROT_LAYOUT)
#define VTOR_TABLE_NS_START_ADDR  0x08100400U
#else
#define VTOR_TABLE_NS_START_ADDR  0x08100000U
#endif

/* USER CODE END VTOR_TABLE*/


static void NonSecure_Init(void);
void SystemClock_Config(void);
static void MPU_Config(void);
/* USER CODE BEGIN 0 */

static void SecurityMpu_ClearOemirotInheritedRegions(void)
{
  uint32_t region;
  uint32_t region_count =
      (MPU->TYPE & MPU_TYPE_DREGION_Msk) >> MPU_TYPE_DREGION_Pos;

  /*
   * JumpHDPLvl3 deliberately hands the application an enabled MPU whose
   * regions constrain the OEMiRoT execution surface.  CubeMX MPU_Config()
   * overwrites region 0 but does not disable the remaining inherited regions.
   * They therefore retain higher priority than the application region and can
   * reject otherwise valid HDPL3 accesses.  Preserve the CubeMX-owned region 0
   * and explicitly retire every boot-stage-only comparator before re-enabling
   * the privileged background map.
   */
  HAL_MPU_Disable();
  for (region = 1U; region < region_count; ++region)
  {
    MPU->RNR = region;
    MPU->RLAR = 0U;
  }
  MPU->RNR = MPU_REGION_NUMBER0;
  HAL_MPU_Enable(MPU_PRIVILEGED_DEFAULT);
  __DSB();
  __ISB();
}

static bool SecurityFDCAN_AttributesAreValid(void)
{
  uint32_t fdcan1_attributes = 0U;
  uint32_t fdcan2_attributes = 0U;
  const uint32_t expected =
      GTZC_TZSC_PERIPH_SEC | GTZC_TZSC_PERIPH_NPRIV;

  return (HAL_GTZC_TZSC_GetConfigPeriphAttributes(
              GTZC_PERIPH_FDCAN1, &fdcan1_attributes) == HAL_OK) &&
         (HAL_GTZC_TZSC_GetConfigPeriphAttributes(
              GTZC_PERIPH_FDCAN2, &fdcan2_attributes) == HAL_OK) &&
         (fdcan1_attributes == expected) &&
         (fdcan2_attributes == expected);
}

/* USER CODE END 0 */

/**
  * @brief  The application entry point.
  * @retval int
  */
int main(void)
{

  /* MCU Configuration--------------------------------------------------------*/

  /* MPU Configuration--------------------------------------------------------*/
  MPU_Config();

  /* Reset of all peripherals, Initializes the Flash interface and the Systick. */
  HAL_Init();

  /* USER CODE BEGIN Init */

  /* Retire OEMiRoT-only MPU regions before Secure services start.  SAU stays
     in the ST H563 OEMiROT application model configured by SystemInit:
     disabled with ALLNS set, with IDAU/Flash watermarks/GTZC authoritative. */
  SecurityMpu_ClearOemirotInheritedRegions();

  /* USER CODE END Init */

  /* Configure the system clock */
  SystemClock_Config();
  /* GTZC initialisation */
  MX_GTZC_S_Init();

  /* USER CODE BEGIN SysInit */

  /* The two 848-byte message-RAM windows straddle a 1 KiB TrustZone boundary.
     Verify ST's mandatory ES0565 2.2.34 workaround before either peripheral
     is initialized; a stale/mismatched attribution must fail closed. */
  if (!SecurityFDCAN_AttributesAreValid())
  {
    Error_Handler();
  }

  /* USER CODE END SysInit */

  /* Initialize all configured peripherals */
  MX_GPIO_Init();
  MX_GPDMA1_Init();
  MX_IWDG_Init();
  MX_ADC1_Init();
  MX_ADC2_Init();
  MX_SPI4_Init();
  MX_FDCAN1_Init();
  MX_FDCAN2_Init();
  MX_TIM4_Init();
  MX_TIM6_Init();
  MX_ICACHE_Init();
  MX_TIM7_Init();
  /* USER CODE BEGIN 2 */
  if (!SecureTimebase_Init())
  {
    Error_Handler();
  }
  if (Safety_ServiceInit() != SAFETY_RESULT_OK)
  {
    Error_Handler();
  }
  /* USER CODE END 2 */

  /*************** Setup and jump to non-secure *******************************/

  NonSecure_Init();

  /* Non-secure software does not return, this code is not executed */

  /* Infinite loop */
  /* USER CODE BEGIN WHILE */
  while (1)
  {
    /* USER CODE END WHILE */

    /* USER CODE BEGIN 3 */
  }
  /* USER CODE END 3 */
}

/**
  * @brief  Non-secure call function
  *         This function is responsible for Non-secure initialization and switch
  *         to non-secure state
  * @retval None
  */
static void NonSecure_Init(void)
{
  funcptr_NS NonSecure_ResetHandler;

  SCB_NS->VTOR = VTOR_TABLE_NS_START_ADDR;

  /* Set non-secure main stack (MSP_NS) */
  __TZ_set_MSP_NS((*(uint32_t *)VTOR_TABLE_NS_START_ADDR));

  /* Get non-secure reset handler */
  NonSecure_ResetHandler = (funcptr_NS)(*((uint32_t *)((VTOR_TABLE_NS_START_ADDR) + 4U)));

  /* Start non-secure state software application */
  NonSecure_ResetHandler();
}

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
 /* MPU Configuration */

void MPU_Config(void)
{
  MPU_Region_InitTypeDef MPU_InitStruct = {0};
  MPU_Attributes_InitTypeDef MPU_AttributesInit = {0};

  /* Disables the MPU */
  HAL_MPU_Disable();

  /** Initializes and configures the Region 0 and the memory to be protected
  */
  MPU_InitStruct.Enable = MPU_REGION_ENABLE;
  MPU_InitStruct.Number = MPU_REGION_NUMBER0;
  MPU_InitStruct.BaseAddress = 0x08FFF000;
  MPU_InitStruct.LimitAddress = 0x08FFFFFF;
  MPU_InitStruct.AttributesIndex = MPU_ATTRIBUTES_NUMBER0;
  MPU_InitStruct.AccessPermission = MPU_REGION_ALL_RO;
  MPU_InitStruct.DisableExec = MPU_INSTRUCTION_ACCESS_DISABLE;
  MPU_InitStruct.IsShareable = MPU_ACCESS_NOT_SHAREABLE;

  HAL_MPU_ConfigRegion(&MPU_InitStruct);

  /** Initializes and configures the Attribute 0 and the memory to be protected
  */
  MPU_AttributesInit.Number = MPU_ATTRIBUTES_NUMBER0;
  MPU_AttributesInit.Attributes = INNER_OUTER(MPU_NOT_CACHEABLE);

  HAL_MPU_ConfigMemoryAttributes(&MPU_AttributesInit);
  /* Enables the MPU */
  HAL_MPU_Enable(MPU_PRIVILEGED_DEFAULT);

}

/**
  * @brief  This function is executed in case of error occurrence.
  * @param None
  * @retval None
  */
void Error_Handler(void)
{
  /* USER CODE BEGIN Error_Handler_Debug */
  /* User can add his own implementation to report the HAL error return state */
  Safety_FaultFromException();
  __disable_irq();
  while (1)
  {
  }
  /* USER CODE END Error_Handler_Debug */
}
#ifdef USE_FULL_ASSERT
/**
  * @brief  Reports the name of the source file and the source line number
  *         where the assert_param error has occurred.
  * @param  file: pointer to the source file name
  * @param  line: assert_param error line source number
  * @retval None
  */
void assert_failed(uint8_t *file, uint32_t line)
{
  /* USER CODE BEGIN 6 */
  /* User can add his own implementation to report the file name and line number,
     ex: printf("Wrong parameters value: file %s on line %d\r\n", file, line) */
  /* USER CODE END 6 */
}
#endif /* USE_FULL_ASSERT */

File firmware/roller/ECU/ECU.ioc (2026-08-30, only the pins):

Mcu.UserName=STM32H563ZITx
PA0.GPIO_Label=SPEED_IN
PA0.Signal=S_TIM2_CH1
PA1.GPIO_Label=RMII_REF_CLK
PA1.Signal=ETH_RMII_REF_CLK
PA13(JTMS/SWDIO).GPIO_Label=SWDIO
PA13(JTMS/SWDIO).Signal=DEBUG_JTMS-SWDIO
PA14(JTCK/SWCLK).GPIO_Label=SWCLK
PA14(JTCK/SWCLK).Signal=DEBUG_JTCK-SWCLK
PA2.GPIO_Label=RMII_MDIO
PA2.Signal=ETH_MDIO
PA3.GPIO_Label=TEMP_SENSOR_1_ADC
PA3.Signal=ADCx_INP15
PA4.GPIO_Label=FWD_VALVE_CURR_ADC
PA4.Signal=ADCx_INP18
PA5.GPIO_Label=TEMP_SENSOR_2_ADC
PA5.Signal=ADCx_INP19
PA6.GPIO_Label=REV_VALVE_CURR_ADC
PA6.Signal=ADCx_INP3
PA7.GPIO_Label=RMII_CRS_DV
PA7.Signal=ETH_RMII_CRS_DV
PB0.GPIO_Label=ENGINE_SENSOR_ADC
PB0.Signal=ADCx_INP9
PB1.GPIO_Label=VBAT_12V_ADC
PB1.Signal=ADCx_INP5
PB12.GPIO_Label=CAN2_RX
PB12.Signal=FDCAN2_RX
PB13.GPIO_Label=CAN2_TX
PB13.Signal=FDCAN2_TX
PB14.GPIO_Label=RMII_NRST
PB14.Signal=GPIO_Output
PB15.GPIO_Label=RMII_TXD1
PB15.Signal=ETH_RMII_TXD1
PB2.GPIO_Label=ESTOP_DETECT
PB2.Signal=GPXTI2
PB6.GPIO_Label=FWD_VALVE_PWM
PB6.Signal=S_TIM4_CH1
PB7.GPIO_Label=REV_VALVE_PWM
PB7.Signal=S_TIM4_CH2
PB8.GPIO_Label=SW_I2C_SDA
PB8.Signal=GPIO_Output
PB9.GPIO_Label=SW_I2C_SCL
PB9.Signal=GPIO_Output
PC0.GPIO_Label=OIL_LEVEL_ADC
PC0.Signal=ADCx_INP10
PC1.GPIO_Label=RMII_MDC
PC1.Signal=ETH_MDC
PC14-OSC32_IN(OSC32_IN).Signal=RCC_OSC32_IN
PC15-OSC32_OUT(OSC32_OUT).Signal=RCC_OSC32_OUT
PC2.GPIO_Label=OIL_TEMP_ADC
PC2.Signal=ADCx_INP12
PC3.GPIO_Label=WATER_LEVEL_ADC
PC3.Signal=ADCx_INP13
PC4.GPIO_Label=RMII_RXD0
PC4.Signal=ETH_RMII_RXD0
PC5.GPIO_Label=RMII_RXD1
PC5.Signal=ETH_RMII_RXD1
PD0.GPIO_Label=CAN1_RX
PD0.Signal=FDCAN1_RX
PD1.GPIO_Label=CAN1_TX
PD1.Signal=FDCAN1_TX
PE2.GPIO_Label=TPIC_SRCK
PE2.Signal=SPI4_SCK
PE3.GPIO_Label=TPIC_OE_N
PE3.Signal=GPIO_Output
PE4.GPIO_Label=TPIC_RCK
PE4.Signal=GPIO_Output
PE5.GPIO_Label=TPIC_CLR_N
PE5.Signal=GPIO_Output
PE6.GPIO_Label=TPIC_SER
PE6.Signal=SPI4_MOSI
PE7.GPIO_Label=TPIC_CTRL_BUF_EN
PE7.Signal=GPIO_Output
PG11.GPIO_Label=RMII_TX_EN
PG11.Signal=ETH_RMII_TX_EN
PG13.GPIO_Label=RMII_TXD0
PG13.Signal=ETH_RMII_TXD0
PH0-OSC_IN(PH0).GPIO_Label=RCC_OSC_IN
PH0-OSC_IN(PH0).Signal=RCC_OSC_IN
PH1-OSC_OUT(PH1).Signal=RCC_OSC_OUT

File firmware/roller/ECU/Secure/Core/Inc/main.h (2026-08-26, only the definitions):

#define TPIC_SRCK_Pin GPIO_PIN_2
#define TPIC_SRCK_GPIO_Port GPIOE
#define TPIC_OE_N_Pin GPIO_PIN_3
#define TPIC_OE_N_GPIO_Port GPIOE
#define TPIC_RCK_Pin GPIO_PIN_4
#define TPIC_RCK_GPIO_Port GPIOE
#define TPIC_CLR_N_Pin GPIO_PIN_5
#define TPIC_CLR_N_GPIO_Port GPIOE
#define TPIC_SER_Pin GPIO_PIN_6
#define TPIC_SER_GPIO_Port GPIOE
#define RCC_OSC_IN_Pin GPIO_PIN_0
#define RCC_OSC_IN_GPIO_Port GPIOH
#define OIL_LEVEL_ADC_Pin GPIO_PIN_0
#define OIL_LEVEL_ADC_GPIO_Port GPIOC
#define RMII_MDC_Pin GPIO_PIN_1
#define RMII_MDC_GPIO_Port GPIOC
#define OIL_TEMP_ADC_Pin GPIO_PIN_2
#define OIL_TEMP_ADC_GPIO_Port GPIOC
#define WATER_LEVEL_ADC_Pin GPIO_PIN_3
#define WATER_LEVEL_ADC_GPIO_Port GPIOC
#define SPEED_IN_Pin GPIO_PIN_0
#define SPEED_IN_GPIO_Port GPIOA
#define RMII_REF_CLK_Pin GPIO_PIN_1
#define RMII_REF_CLK_GPIO_Port GPIOA
#define RMII_MDIO_Pin GPIO_PIN_2
#define RMII_MDIO_GPIO_Port GPIOA
#define TEMP_SENSOR_1_ADC_Pin GPIO_PIN_3
#define TEMP_SENSOR_1_ADC_GPIO_Port GPIOA
#define FWD_VALVE_CURR_ADC_Pin GPIO_PIN_4
#define FWD_VALVE_CURR_ADC_GPIO_Port GPIOA
#define TEMP_SENSOR_2_ADC_Pin GPIO_PIN_5
#define TEMP_SENSOR_2_ADC_GPIO_Port GPIOA
#define REV_VALVE_CURR_ADC_Pin GPIO_PIN_6
#define REV_VALVE_CURR_ADC_GPIO_Port GPIOA
#define RMII_CRS_DV_Pin GPIO_PIN_7
#define RMII_CRS_DV_GPIO_Port GPIOA
#define RMII_RXD0_Pin GPIO_PIN_4
#define RMII_RXD0_GPIO_Port GPIOC
#define RMII_RXD1_Pin GPIO_PIN_5
#define RMII_RXD1_GPIO_Port GPIOC
#define ENGINE_SENSOR_ADC_Pin GPIO_PIN_0
#define ENGINE_SENSOR_ADC_GPIO_Port GPIOB
#define VBAT_12V_ADC_Pin GPIO_PIN_1
#define VBAT_12V_ADC_GPIO_Port GPIOB
#define ESTOP_DETECT_Pin GPIO_PIN_2
#define ESTOP_DETECT_GPIO_Port GPIOB
#define TPIC_CTRL_BUF_EN_Pin GPIO_PIN_7
#define TPIC_CTRL_BUF_EN_GPIO_Port GPIOE
#define CAN2_RX_Pin GPIO_PIN_12
#define CAN2_RX_GPIO_Port GPIOB
#define CAN2_TX_Pin GPIO_PIN_13
#define CAN2_TX_GPIO_Port GPIOB
#define RMII_NRST_Pin GPIO_PIN_14
#define RMII_NRST_GPIO_Port GPIOB
#define RMII_TXD1_Pin GPIO_PIN_15
#define RMII_TXD1_GPIO_Port GPIOB
#define SWDIO_Pin GPIO_PIN_13
#define SWDIO_GPIO_Port GPIOA
#define SWCLK_Pin GPIO_PIN_14
#define SWCLK_GPIO_Port GPIOA
#define CAN1_RX_Pin GPIO_PIN_0
#define CAN1_RX_GPIO_Port GPIOD
#define CAN1_TX_Pin GPIO_PIN_1
#define CAN1_TX_GPIO_Port GPIOD
#define RMII_TX_EN_Pin GPIO_PIN_11
#define RMII_TX_EN_GPIO_Port GPIOG
#define RMII_TXD0_Pin GPIO_PIN_13
#define RMII_TXD0_GPIO_Port GPIOG
#define FWD_VALVE_PWM_Pin GPIO_PIN_6
#define FWD_VALVE_PWM_GPIO_Port GPIOB
#define REV_VALVE_PWM_Pin GPIO_PIN_7
#define REV_VALVE_PWM_GPIO_Port GPIOB
#define SW_I2C_SDA_Pin GPIO_PIN_8
#define SW_I2C_SDA_GPIO_Port GPIOB
#define SW_I2C_SCL_Pin GPIO_PIN_9
#define SW_I2C_SCL_GPIO_Port GPIOB

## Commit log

2024-12-26 Created repo and point submodule slv_ardupilot to slv branch.
    [AuxSim.sch, CntDiffAmp0.sch, CntDiffAmp0_tb.sch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]
2025-04-23 Refactor code structure and remove redundant sections
    [BiasReceiver-B_Cu.gbr, BiasReceiver-B_Mask.gbr, BiasReceiver-Edge_Cuts.gbr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]
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2025-04-23 Fix odometry calculations: negate left encoder counts in initialization, update, reset, and data retrieval functions
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2025-04-28 Implement communication protocol and integrate encoder data publishing
    - Added protocol.c to handle communication protocol implementation.
    - Introduced functions for packing and unpacking various data types including encoder parameters, GPS parameters, and EKF data.
    - Updated main.c to publish encoder data over TCP, including encoder parameters and counts.
    - Implemented CRC-8 checksum calculation for data integrity.
    - Enhanced data handling by defining expected packet sizes and managing data buffers for different frame types.
2025-04-28 Refactor encoder data handling: unify frame type and update data structure for multiple encoder counts
2025-04-28 Refactor encoder data packing: remove frame type parameter and set it internally
2025-04-28 Refactor protocol: update frame counts for GPS raw and position data, rename packing function for clarity
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2025-04-28 Fix TIM2 initialization: correct timer period value from 4294967295 to 65535
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2025-04-29 Refactor odometry data structure and update related functions
    - Changed odometry data structure from `odometry_t` to `odometry_data_t` for clarity and consistency.
    - Updated odometry initialization, update, and reset functions to reflect the new data structure.
    - Modified odometry calculations to use new parameters such as `encoder_pulse_per_rev` and `gear_ratio`.
    - Updated protocol functions to pack and parse odometry data correctly.
    - Adjusted main application logic to handle the new odometry data structure and send odometry data over TCP.
    - Refined parameter handling to replace `encoder_resolution` with `encoder_pulse_per_rev` and `time_scaling` with `gear_ratio`.
    - Updated CAN and ROS da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
2025-04-29 Refactor odometry module: replace odometry data structure with separate wheel odometry and encoder data handling functions
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2025-05-14 Refactor EKF process noise parameters: adjust uncertainties for position, yaw, velocity, and angular velocity in fusion.c; update odometry handling in main.c to improve data management and logging.
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2025-09-25 fix: Correct UART instance assignments for GPS data reception
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2026-07-05 fix: Update ADC and USART pin definitions; add temperature vs resistance table
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2026-07-05 Add TCP communication node for data exchange with server
    - Implement TcpCommNode class for handling TCP connections.
    - Initialize parameters for server IP, port, and reconnection settings.
    - Create publishers and subscribers for sending and receiving data.
    - Implement connection management with error handling and reconnection logic.
    - Add functions for sending LED commands and processing received data.
    - Integrate NTRIP client for differential correction data transmission.
    - Convert received MMW data to LaserScan messages for publishing.
    - Ensure thread safety with mutexes for shared resources.
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2026-07-13 feat: Implement power handoff mechanism in bootloader
    - Add boot_reset.s to handle system reset and power management during boot.
    - Update boot_update_server.c to request power handoff before resetting.
    - Introduce ccu_power_handoff.h and ccu_power_handoff.c for managing power states.
    - Modify GPIO initialization in ccu_gpio.c to respect power handoff settings.
    - Update linker scripts to reserve SRAM for power handoff data.
    - Document bootloader power hold behavior and ROS2 topic specifications.
    - Validate OTA update process and ensure proper state management during transitions.
2026-07-14 Add documentation, tests, and enhancements for GPS and Ethernet functionality
    - Created a new document for CubeMX UART RX pull-up configuration to prevent false start bits during GPS initialization.
    - Updated the Ethernet firmware update documentation to clarify the testing process and Bootloader behavior.
    - Added a new document for GPS UTC and OTA validation, detailing test results and performance metrics.
    - Introduced a shell script to run host tests for GPS application functionality.
    - Implemented a new test file for GPS application parsing, including various test cases for AGRICA messages.
    - Enhanced the STM32 update tool to log Bootloader version and metadata during updates.
    - Modified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
2026-07-29 fix: update text label in Power.kicad_sch for clarity and adjust position
2026-07-29 Add initial KiCad project file for ECU design
    - Created a new KiCad project file (ecu.kicad_pro) for the ECU design.
    - Configured board settings, including layer pairs, net settings, and schematic annotations.
    - Defined ERC rules and library settings for components.
    - Established BOM export settings and drawing configurations.
    [01_Power.kicad_sch, 02_MCU_Core.kicad_sch, 03_Ethernet.kicad_sch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]
2026-07-29 Add power symbols for +1V0 and PWR_FLAG to the schematic
    - Introduced a new global power symbol for +1V0 with appropriate properties and pin configurations.
    - Added a PWR_FLAG symbol to indicate power source in the schematic, enhancing ERC capabilities.
    - Updated the used designators in the project file to include new power symbols.
    [01_Power.kicad_sch, 02_MCU_Core.kicad_sch, 03_Ethernet.kicad_sch]
2026-07-29 Add design settings and DRC rules to ECU PCB configuration
    - Introduced comprehensive design settings including defaults for various parameters such as line widths, text sizes, and pad dimensions.
    - Added detailed DRC (Design Rule Check) exclusions and rule severities to enhance error handling and warnings during PCB design.
    - Updated tuning pattern settings and teardrop parameters for improved track and pad connections.
    - Cleared previously used designators for better organization and clarity in the design file.
    [02_MCU_Core.kicad_sch, 03_Ethernet.kicad_sch, 04_CAN.kicad_sch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]
2026-07-30 Add ESTOP_NC pin and wire connections in ECU schematic; update designators in PCB project
    [01_Power.kicad_sch, 02_MCU_Core.kicad_sch, 04_CAN.kicad_sch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]
2026-07-30 fix: update resistor value from 887k to 510k in Power.kicad_sch
2026-07-30 Refactor ECU schematic and project files
    - Updated used designators in ecu.kicad_pro to reflect current components.
    - Adjusted wire connections in ecu.kicad_sch for better layout and clarity.
    - Added new wires and labels for ESTOP functionality.
    - Modified pin placements and sizes for improved organization in the schematic.
    - Ensured all changes maintain compatibility with existing design specifications.
    [02_MCU_Core.kicad_sch, 06_Relay.kicad_sch, 08_Sensors.kicad_sch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]
2026-07-30 refactor: update PCB design settings and layer configurations in ECU files
    [ecu.kicad_pcb]
2026-07-30 fix: adjust silk screen positions for J7 and J6 in ECU PCB layout
    [ecu.kicad_pcb]
2026-07-31 Implement code changes to enhance functionality and improve performance
    [06_Relay.kicad_sch, 09_Connectors.kicad_sch, ecu.kicad_pcb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]
2026-07-31 fix: update power symbol and reference designators in ECU schematic and PCB files
    [09_Connectors.kicad_sch, ecu.kicad_pcb]
2026-07-31 fix: update net name from "+BAT" to "+12V" in ECU PCB file
    [ecu.kicad_pcb]
2026-08-06 Enhance ECU design files with updated parameters and new libraries
    - Updated `ecu.kicad_pro` with new zone parameters, track widths, and DRC rules to improve design flexibility and manufacturability.
    - Added `erc_report.json` to capture electrical rule check results, including warnings for multiple net names.
    - Introduced `fp-lib-table` and `sym-lib-table` to include project-local libraries for footprints and symbols, enhancing design organization and accessibility.
    [02_MCU_Core.kicad_sch, 03_Ethernet.kicad_sch, ecu.kicad_pcb]
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2026-08-07 feat: update ECU 4-layer layout and fabrication profile
    [02_MCU_Core.kicad_sch, 09_Connectors.kicad_sch, ecu.kicad_pcb]
2026-08-10 Refactor ECU schematic: Adjust wire connections and update no_connect points
    - Modified coordinates for several no_connect points to improve layout clarity.
    - Adjusted wire connections to reflect updated schematic design.
    - Removed redundant wire segments and ensured UUIDs are consistent with changes.
    - Enhanced overall readability and organization of the schematic for better maintenance.
    [ecu.kicad_pcb, ecu.kicad_sch]
2026-08-11 Refactor QFN-234MMX5MM_MPQ4371_MNP footprint: Update pad definitions to custom shapes with mesh-connect lands, adjust silk layer properties, and enhance pad geometries for improved thermal performanc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
    [ecu.kicad_pcb]
2026-08-12 Add new resistor value and update used designators in ECU schematic
    - Added a new resistor value of 0.8 to the list of available values.
    - Updated the used designators to include J7 in the ECU schematic.
    [09_Connectors.kicad_sch, ecu.kicad_pcb]
2026-08-13 Implement feature X to enhance user experience and fix bug Y in module Z
    [ecu.kicad_pcb]
2026-08-14 Implement new feature for user authentication and improve error handling
    [ecu.kicad_pcb]
2026-08-14 Update used_designators in ecu.kicad_pro to include resistors R113-115
    [03_Ethernet.kicad_sch, 09_Connectors.kicad_sch, ecu.kicad_pcb]
2026-08-14 Add Ethernet segments and tuning pattern to ECU PCB layout
    [ecu.kicad_pcb]
2026-08-14 Change silk edge clearance rule from warning to error in ECU PCB design
    [ecu.kicad_pcb]
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2026-08-29 Refactor ECU programming script and add OEMiROT provisioning tool
    - Updated `program_ecu.sh` to support dynamic build types and variants for secure and non-secure images.
    - Enhanced backup functionality for persistent storage and added verification steps.
    - Introduced `provision_oemirot_open.sh` for provisioning the STM32H563 ECU with an OEMiROT boot chain while in an open state.
    - Implemented various checks and balances for option bytes and runtime authentication during provisioning.
    - Added tests for SHA-256 security functions in `test.sh` to ensure integrity and correctness.
    [flash_layout.h, gtzc_s.c, icache.c]
2026-08-30 Add scripts for validating ECU firmware and pairing store
    - Introduced `verify_open_loader_backup.py` to validate paired primary images before an OPEN loader update, ensuring integrity and correctness of firmware images.
    - Added `verify_pairing_store.py` to verify the integrity of the ECU's ATECC pairing-record sectors, checking for expected values and ensuring redundancy.
    [ECU.ioc, eth.c, gtzc_s.c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]
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2026-09-05 feat(ecu): finalize 1.0.20 safety controls and bench acceptance
    Add K12 run-permit policy, latched network E-stop reset, multi-source control handling, and NSC ABI v4. Harden physical-E-stop OTA gating, signed image alignment, and release verification.
    Update debug UI and host bench guards; add network acceptance and volatile PI comparison tools. Record SN-EJAHGJI OTA, valve tests, generation-3 PI persistence, cold boot, and latency results without changing valve firmware defaults.
    Validation: 238 Python/static tests, configuration audit, and diff checks pass. Native C behavior tests unavailable on this host; ARM compile-only checks passed. Private keys, firmware artifacts, and raw hardwar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
    [safety_api.h]
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2026-09-14 feat: add abstract project
    [01_Power.kicad_sch, 02_MCU_Core.kicad_sch, 03_Ethernet.kicad_sch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]
2026-09-14 fix: optimize abstract net label placement
    [PAGE1.kicad_sch, PAGE2.kicad_sch, PAGE3.kicad_sch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]
2026-09-14 fix: preserve schematic net semantics
    [PAGE1.kicad_sch, PAGE2.kicad_sch, PAGE3.kicad_sch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]
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

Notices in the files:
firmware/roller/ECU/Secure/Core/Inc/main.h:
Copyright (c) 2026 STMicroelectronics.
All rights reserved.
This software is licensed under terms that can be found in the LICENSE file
